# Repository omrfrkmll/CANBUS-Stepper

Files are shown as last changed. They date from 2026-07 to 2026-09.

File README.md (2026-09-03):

# ⚡ CANBUS-Stepper

<p align="center">
  <b>ESP32-S3 Based Closed-Loop Smart CAN Bus Stepper Motor Driver Board (v1.1)</b>
</p>

<p align="center">
  
  
  
  
  
  
  
</p>

<p align="center">
  <a href="#-overview">Overview</a> •
  <a href="#-development-status">Development Status</a> •
  <a href="#-hardware-features--specifications">Hardware Specs</a> •
  <a href="#-pcb--hardware-preview">PCB Preview</a> •
  <a href="#-schematics--mechanical-cad">Schematic & CAD</a> •
  <a href="#-firmware--control-sdk">Firmware & SDK</a> •
  <a href="#-official-hardware--custom-engineering">Official Hardware & Services</a> •
  <a href="#-license">License</a>
</p>

---

## 📌 Overview

**CANBUS-Stepper** is a high-performance smart stepper motor driver board powered by the **ESP32-S3** dual-core microcontroller. Designed specifically for 3D printer toolheads, robotic actuators, AGVs, CNC axes, and industrial automation, this board integrates:

- **Ultra-Quiet Motor Drive**: Trinamic TMC2209-LA driver with StealthChop2™, SpreadCycle™, and StallGuard4™ sensorless homing.
- **Closed-Loop Position Feedback**: High-precision AS5600 12-bit magnetic rotary encoder mounted coaxially on the bottom layer to eliminate missed steps.
- **Native CAN Bus Communication**: Automotive-grade TI TCAN3413 transceiver supporting high-speed CAN and CAN FD logic with 3.3V logic.
- **Industrial Wide-Input Power**: High-efficiency TI LMR33630 36V / 3A synchronous step-down DC-DC buck regulator + ultra-low-noise 3.3V LDO.
- **Multi-Stage Protection Circuits**: Reverse polarity P-MOSFET, transient voltage suppressors (TVS), ESD diode arrays, and resettable PPTC fuses.
- **Compact NEMA 17 Footprint**: Fits directly onto the rear face of standard 42mm x 42mm NEMA 17 stepper motors (40.3mm x 40.3mm profile with corner chamfers and M3 mounting holes).

---

## 🚧 Development Status

| Component | Status | Details |
| :--- | :---: | :--- |
| **Schematic Design** | ✅ Complete | Hierarchical schematic design, [PDF export available](docs/schematics/CANBUS_Stepper_v1.1_Schematic.pdf) |
| **PCB Layout (v1.1)** | ✅ Complete | 2-Layer 1.6mm FR4, DRC clean, planar ESP32-S3 pin routing |
| **Component Mapping (BOM)** | ✅ Complete | 43 unique lines / 67 components 100% mapped with LCSC part numbers |
| **3D CAD STEP Models** | ✅ Complete | Exported 3D assembly ([`step/canbus-stepper-v1.1.step`](step/canbus-stepper-v1.1.step)) ready for enclosure design |
| **Physical Prototyping** | 🔄 In Progress | Prototype PCBA fabrication & physical hardware bring-up |
| **Firmware & Control SDK** | 🔄 In Progress | ESP32-S3 TWAI CAN driver, closed-loop PID loop & Klipper node support |

---

## 🛠️ Hardware Features & Specifications

### 🧠 Core System & Processing
- **MCU**: **ESP32-S3-MINI-1-N4R2** (Dual-core Xtensa® 32-bit LX7 @ 240 MHz, 2.4 GHz Wi-Fi 4 + Bluetooth 5 LE, 4 MB Flash, 2 MB Quad SPI PSRAM).
- **USB Interface**: Native Full-Speed USB 2.0 via Type-C connector with hardware CDC serial console & JTAG debugging support.

### ⚡ Motor Drive & Closed-Loop Regulation
- **Stepper Driver**: **Trinamic TMC2209-LA** (VQFN-28 package with thermal vias).
  - Operating Voltage: Up to 28V DC (recommended 12V – 24V).
  - Current Capability: 2.0A RMS (2.8A Peak) motor phase current.
  - Features: StealthChop2™ (silent operation), SpreadCycle™ (high dynamic torque), StallGuard4™ (load measurement & sensorless homing), CoolStep™ (energy saving).
  - Interface: UART control for dynamic microstepping configuration (up to 256 microsteps) and real-time current scaling.
- **Position Sensor**: **AMS AS5600-ASOT** 12-Bit On-Axis Magnetic Rotary Encoder.
  - Position Resolution: 4096 steps/rev (0.087° resolution).
  - Mounting: Centered directly on PCB bottom layer for coaxial alignment with motor shaft diametral magnet.
  - Interface: Fast-mode I2C (400 kHz).

### 🌐 Bus Communication & Power Regulation
- **CAN Bus Transceiver**: **TI TCAN3413DRBR** 3.3V CAN FD Transceiver with 3.3V V_IO logic interface and ±58V bus fault protection.
- **Main DC-DC Buck Converter**: **TI LMR33630CRNXR** Synchronous Step-Down Regulator (3.8V – 36V input range, 3.0A continuous output @ 2.1 MHz switching frequency) with **Changjiang FNR4020S4R7MT** (4.7µH / 2A) shielded power inductor.
- **MCU & Analog LDO**: **TI TLV75533PDRVR** 500mA ultra-low-dropout 3.3V regulator providing clean power to ESP32-S3 and sensors.
- **Bulk Filtering**: 100µF / 35V Low-ESR aluminum electrolytic bulk capacitor (6.3mm x 5.8mm SMD) for motor switching current ripple suppression.

### 🛡️ Protection & Safety Architecture
- **Reverse Polarity Protection**: **AON7403** (-30V / -50A, 8.5mΩ R_DS(on) P-Channel MOSFET) with Zener gate clamping.
- **Overcurrent Protection**:
  - 1.5A / 24V Resettable PPTC fuse (`1210L150/24WR`) on main 24V DC input rail.
  - 500mA / 16V Resettable PPTC fuse (`SMDH0805B050TF`) on USB VBUS power line.
- **Transient & ESD Protection**:
  - **PESD1CAN** TVS diode array on CAN Bus differential lines (CAN_H / CAN_L).
  - **SMAJ28A** 28V / 400W Transient Voltage Suppressor on main 24V DC input.
  - **STMicroelectronics USBLC6-2P6** ultra-low capacitance ESD protection array on USB D+/D- lines.
  - **MBR0520** Schottky diode for safe USB/Main power OR-ing.

### 🔌 Connectors, Ports & Controls
| Connector / Component | Type / Footprint | Function |
| :--- | :--- | :--- |
| **USB-C** | 16-Pin USB Type-C Receptacle | Firmware flashing, USB CDC serial debugging & power |
| **24V Power In / Out** | 2x Molex Micro-Fit 3.0 (436500209) 2-Pin | 24V Main power input & daisy-chain pass-through |
| **Motor Output** | JST PH 4-Pin SMD (S4B-PH-SM4-K-TB) | 4-wire bipolar stepper motor phases (A1, A2, B1, B2) |
| **Qwiic / I2C Port** | JST SH 4-Pin (1.0mm) Horizontal | External I2C sensors, OLED displays & expansions (3.3V, GND, SDA, SCL) |
| **AUX Port** | JST SH 4-Pin (1.0mm) Horizontal | Auxiliary GPIOs for endstops, bed probes, or toolhead sensors |
| **CAN Bus In / Out** | 2x JST SH 2-Pin (SM02B-SRSS-TB) | CAN Bus differential input & daisy-chain pass-through (CAN_H, CAN_L) |
| **OLED Display FPC** | Amphenol SFV30R-2STBE1HLF (30-Pin 0.5mm) | Bare COG OLED display panel interface (SSD1306) |
| **CAN Termination** | SMD Slide Switch (`MSK12C01G15-W`) | Switchable 120Ω CAN bus termination resistor |
| **Buttons & Indicators** | 2x Tactile Push-Buttons + 3x LEDs | RESET, BOOT/User buttons; Power, Driver, and CAN Status LEDs |

---

## 🖼️ PCB & Hardware Preview

<p align="center">
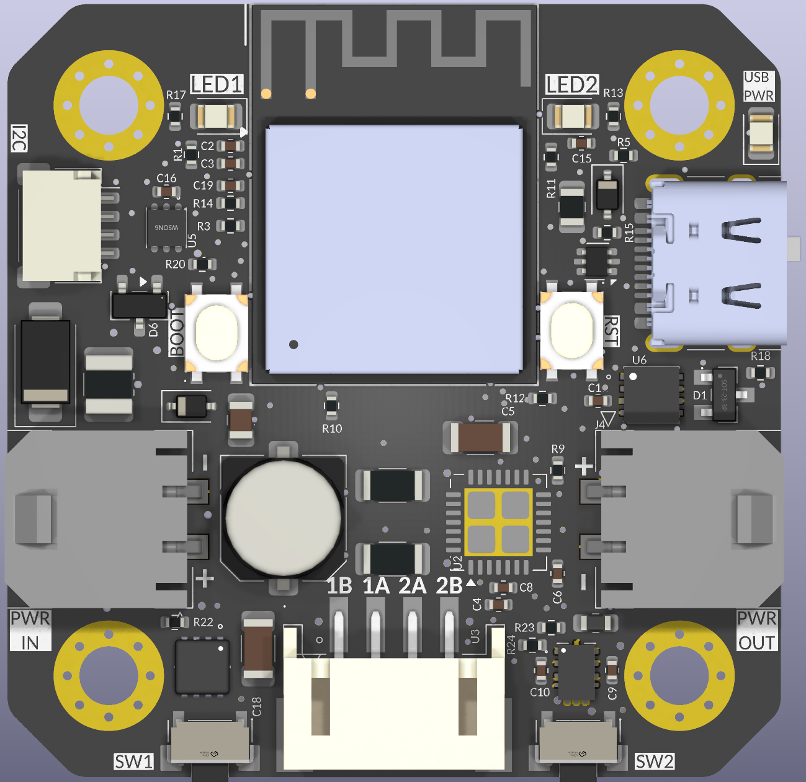
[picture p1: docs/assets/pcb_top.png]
CANBUS-Stepper PCB Top Side
  
  &nbsp;&nbsp;
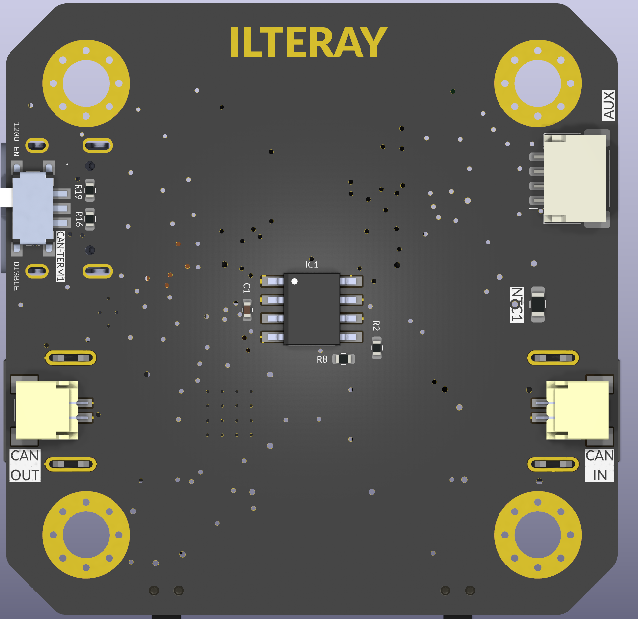
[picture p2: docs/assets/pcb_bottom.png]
CANBUS-Stepper PCB Bottom Side
  
  <br>
  <i>Figure 1: CANBUS-Stepper v1.1 Component Layout — Top Layer (Left) & Bottom Layer (Right)</i>
</p>

---

## 📄 Schematics & Mechanical CAD

To enable seamless third-party software integration, driver development, and custom enclosure modeling, official hardware reference documents are provided:

1. **Schematic Circuit Diagrams (PDF)**:
   - Complete multi-sheet reference schematics are available in [`docs/schematics/CANBUS_Stepper_v1.1_Schematic.pdf`](docs/schematics/CANBUS_Stepper_v1.1_Schematic.pdf) (Legacy v1.0 available in [`docs/schematics/`](docs/schematics/)).
   - Details MCU pinouts, TMC2209 UART buses, CAN transceiver wiring, protection circuits, and sensor connectors.
2. **3D Mechanical STEP Assembly**:
   - Ready-to-import 3D CAD model: [`step/canbus-stepper-v1.1.step`](step/canbus-stepper-v1.1.step).
   - Accurate component heights, connector positions, and NEMA 17 rear mounting hole spacing (31.0mm x 31.0mm diagonal M3 holes).

---

## 📁 Repository Structure

```
CANBUS-Stepper/
├── README.md                      # Main project documentation & specifications
├── LICENSE                        # CC BY-NC-SA 4.0 (Hardware Reference) & MIT (Software)
├── .gitignore                     # Git ignore rules
├── docs/
│   ├── assets/                    # 3D PCB renders, board photos, and diagrams
│   └── schematics/                # Full PDF Schematic & Pinout reference documentation
│       ├── README.md              # Sheet breakdown and integration guide
│       └── CANBUS_Stepper_v1.1_Schematic.pdf
├── firmware/                      # ESP32-S3 Firmware, Protocol & SDK
│   ├── include/                   # Drivers, control loops, and headers
│   ├── src/                       # Motion controller, TWAI CAN, AS5600, TMC2209
│   ├── klipper/                   # Klipper toolhead configuration & docs
│   ├── platformio.ini             # PlatformIO build configuration
│   └── README.md                  # Firmware architecture & roadmap
└── step/                          # 3D CAD STEP Files for mechanical integration
    ├── canbus-stepper-v1.1.step   # Full 3D PCB assembly STEP model (v1.1)
    └── README.md                  # Mounting specifications & CAD guide
```

---

## 🧠 Firmware & Control SDK

The ESP32-S3 microcontroller firmware is developed under `firmware/` and targets both standalone robotic motion control and 3D printing ecosystems:

- **TWAI CAN Protocol**: High-speed command parser for position target streaming, velocity profiling, and status telemetry.
- **Closed-Loop PID Loop**: High-frequency reading from the AS5600 magnetic encoder with real-time step error correction and missed step prevention.
- **Klipper CAN Toolhead Support**: Compatibility with Klipper firmware for plug-and-play toolhead CAN node integration.
- **ROS2 & Micro-ROS**: Direct actuator node integration for robotic arms, wheeled rovers, and multi-axis mechanisms.
- **Open SDK**: Python and C++ driver libraries for controlling motors over USB-to-CAN adapters.

---

## 🛒 Official Hardware, Kits & Custom Engineering

Ensure guaranteed hardware quality and support ongoing development through **Official Pre-Assembled Hardware & Engineering Services**:

### 📦 Official Plug-and-Play Kits
- 🛠️ **Factory-Tested Boards**: 100% SMT assembled, flashed with factory test firmware, and validated under motor load.
- 🧲 **Complete Motor Kits**: Bundled with high-temperature NEMA 17 stepper motors, matched diametrically magnetized shaft magnets, 3D printed mounting brackets, and pre-crimped Molex/JST wire harnesses.
- ☕ **Support Ongoing Development**: Official hardware sales directly fund continuous firmware development, Klipper modules, and future hardware revisions.

### 🏢 B2B Custom Robotics & Turnkey Engineering
Need customized hardware or industrial integration for your commercial robotics or automation project?
- **Custom PCB Redesigns** (Multi-axis drivers, 48V high-voltage input, RS485 / EtherCAT / DroneCAN).
- **Industrial Firmware & ROS2 / Micro-ROS Drivers**.
- **Volume Batch Manufacturing & PCBA Sourcing**.

👉 *For pre-orders, volume batch requests, or custom engineering consulting, please reach out via GitHub Issues or contact the maintainer.*

---

## 📜 License

This project follows a **Hybrid Open-Software & Reference-Hardware** model:

- 🛡️ **Hardware Reference (Schematics, Pinouts, Mechanical Specs & 3D STEP)**: [Creative Commons Attribution-NonCommercial-ShareAlike 4.0 International (CC BY-NC-SA 4.0)](https://creativecommons.org/licenses/by-nc-sa/4.0/).
- 💻 **Firmware & Software Stack**: [MIT License](LICENSE).
- 🏷️ **Trademarks & Official Branding**: The "CANBUS-Stepper" and "ILTERAY" names and logos represent official tested hardware.

---

<p align="center">
  <b>CANBUS-Stepper</b> • Open-Source Smart Motion Control
</p>

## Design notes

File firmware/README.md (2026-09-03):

# 🧠 CANBUS-Stepper Firmware & Control SDK

This directory contains the firmware architecture, CAN bus communication protocol, and control SDK for the **ESP32-S3** microcontroller on the **CANBUS-Stepper** closed-loop driver board.

---

## 🏗️ Architecture & Core Components

- **Target MCU**: ESP32-S3-MINI-1-N4R2 (Dual-core Xtensa LX7 @ 240MHz, 4MB Flash, 2MB PSRAM)
- **Framework**: ESP-IDF v5.x / Arduino ESP32 Core
- **Motor Control**: Trinamic TMC2209-LA via UART (microstepping, StealthChop2, StallGuard4 sensorless homing) + Step/Dir pulse generation.
- **Closed-Loop Feedback**: AS5600 12-Bit Magnetic Rotary Encoder via fast hardware I2C (400kHz), running high-frequency angle reading & real-time PID position error correction.
- **Communication Stack**: ESP32-S3 Native TWAI (Two-Wire Automotive Interface) CAN Bus driver via TI TCAN3413 transceiver.

---

## 🗺️ Firmware Development Roadmap

- [ ] **Phase 1: Board Bring-up & Diagnostics**
  - [x] Hardware pinout mapping & peripheral definitions.
  - [ ] Power rail validation, I2C bus scanner (AS5600 detection & magnet field strength check).
  - [ ] TMC2209 UART communication & register read/write tests.
  - [ ] Native USB CDC serial console & web flasher integration.

- [ ] **Phase 2: Motor Motion & Closed-Loop Control**
  - [ ] High-frequency RMT / Timer-based step pulse generation with acceleration curves.
  - [ ] Closed-loop PID position regulator using AS5600 feedback.
  - [ ] Stall detection, missed step recovery, and overload protection.

- [ ] **Phase 3: Bus Protocols & Ecosystem Integration**
  - [ ] Standardized CAN Bus binary packet protocol (Position, Velocity, Current, Status telemetry).
  - [ ] **Klipper CAN Bus Toolhead / Stepper Node** protocol compatibility.
  - [ ] **Micro-ROS / ROS2** actuator node support for robotic arms and AGVs.
  - [ ] Open-source Python & C++ client SDKs with GUI motor tuning tools.

---

## 🤝 Contributing
Firmware contributions, issue reports, and feature requests are warmly welcomed! Please refer to the main repository [LICENSE](../LICENSE) (MIT License).

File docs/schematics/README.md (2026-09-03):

# 📄 CANBUS-Stepper Hardware Schematics

This directory contains the official reference schematic diagrams for the **CANBUS-Stepper** smart closed-loop stepper motor driver board.

## 📑 Available Documentation

- **v1.1 Schematic Diagram (PDF - Latest)**: [`CANBUS_Stepper_v1.1_Schematic.pdf`](CANBUS_Stepper_v1.1_Schematic.pdf)
  - Updated ESP32-S3 planar pinout & non-crossing routing optimization
  - Sheet 1: ESP32-S3-MINI-1 Microcontroller, USB Type-C & Power OR-ing
  - Sheet 2: Trinamic TMC2209-LA Motor Driver & Current Sensing
  - Sheet 3: AS5600 12-bit Magnetic Encoder & Sensor Interfaces (Qwiic, NTC, AUX)
  - Sheet 4: TI TCAN3413 CAN FD Transceiver & 120Ω Switchable Termination
  - Sheet 5: TI LMR33630 36V/3A DC-DC Buck Converter, Protection & 3.3V LDO
- **v1.0 Schematic Diagram (PDF - Legacy)**: [`CANBUS_Stepper_v1.0_Schematic.pdf`](CANBUS_Stepper_v1.0_Schematic.pdf)

## 🛡️ License & Usage

- **Schematics & Pinout Reference**: Licensed under [Creative Commons Attribution-NonCommercial-ShareAlike 4.0 (CC BY-NC-SA 4.0)](https://creativecommons.org/licenses/by-nc-sa/4.0/).
- For commercial hardware manufacturing inquiries, official pre-assembled boards, or volume orders, please contact the maintainers.

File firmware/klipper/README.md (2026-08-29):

# 🖨️ Klipper & Katapult (CanBoot) Setup Guide

This guide explains how to compile and flash **Klipper** or **Katapult (CanBoot)** onto the **CANBUS-Stepper v1.1** board to use it as a high-speed CAN bus stepper / toolhead node in 3D printers and CNC machines.

---

## 🛠️ 1. Compiling Katapult Bootloader

Katapult allows future firmware updates to be flashed directly over the CAN bus without plugging in a USB cable.

1. Clone Katapult:
   ```bash
   git clone https://github.com/Arksine/katapult
   cd katapult
   make menuconfig
   ```

2. Configure Katapult settings for **ESP32-S3**:
   - **Micro-controller Architecture**: `Espressif ESP32`
   - **Processor model**: `esp32s3`
   - **Communication interface**: `CAN bus`
   - **CAN RX gpio number**: `47`
   - **CAN TX gpio number**: `48`
   - **CAN bus speed**: `500000` (or `1000000` for 1M)
   - **Status LED pin**: `10`

3. Compile and flash over USB:
   ```bash
   make
   esptool.py --chip esp32s3 -p /dev/ttyACM0 write_flash 0x0 out/katapult.bin
   ```

---

## 🚀 2. Compiling Klipper MCU Firmware

1. Open Klipper menuconfig:
   ```bash
   cd ~/klipper
   make menuconfig
   ```

2. Select the following parameters:
   - **Enable extra low-level configuration options**: `[ * ]`
   - **Micro-controller Architecture**: `Espressif ESP32`
   - **Processor model**: `esp32s3`
   - **Communication interface**: `CAN bus`
   - **CAN RX gpio number**: `47`
   - **CAN TX gpio number**: `48`
   - **CAN bus speed**: `500000` (or your CAN network speed)

3. Compile Klipper:
   ```bash
   make
   ```

4. Flash Klipper over CAN Bus via Katapult:
   ```bash
   python3 ~/katapult/scripts/flashtool.py -i can0 -u <YOUR_CANBUS_UUID> -r
   python3 ~/katapult/scripts/flashtool.py -i can0 -u <YOUR_CANBUS_UUID> -f ~/klipper/out/klipper.bin
   ```

---

## 📄 3. Integrating with `printer.cfg`

Copy the provided [`canbus_stepper_klipper.cfg`](canbus_stepper_klipper.cfg) configuration into your Klipper configuration directory and include it in `printer.cfg`:

```ini
[include canbus_stepper_klipper.cfg]
```

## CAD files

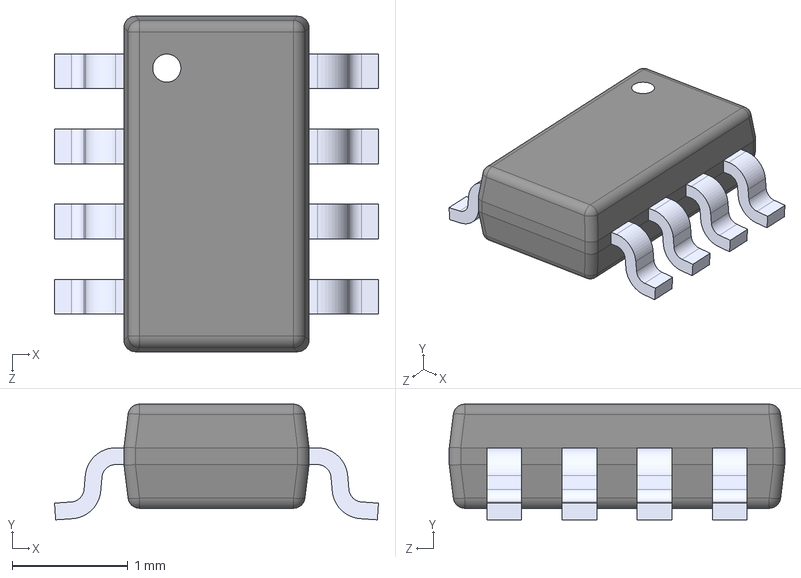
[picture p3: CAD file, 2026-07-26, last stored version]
3dmodels/MP2315GJ.step
2.80 x 1 x 2.90 mm

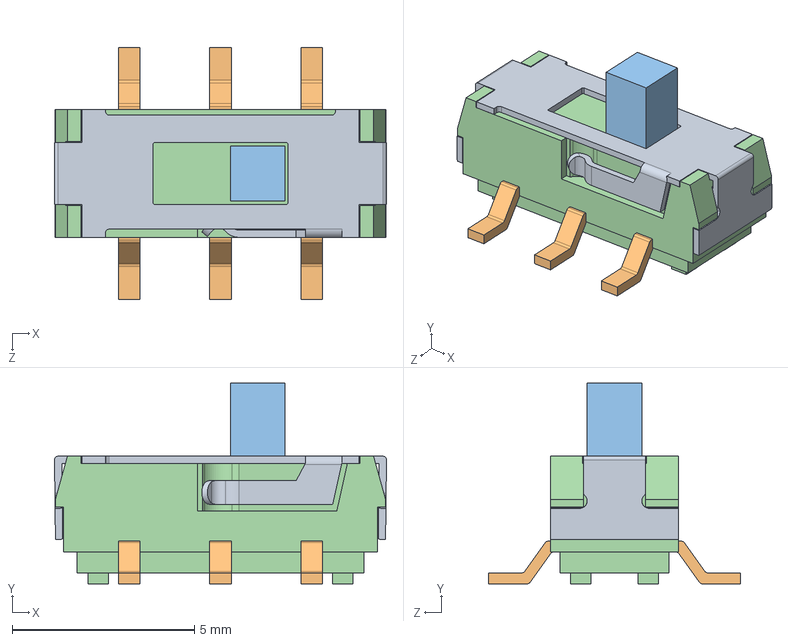
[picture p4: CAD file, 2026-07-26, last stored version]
3dmodels/SLW-913535-2A-SMT.step
9.10 x 5.50 x 6.90 mm

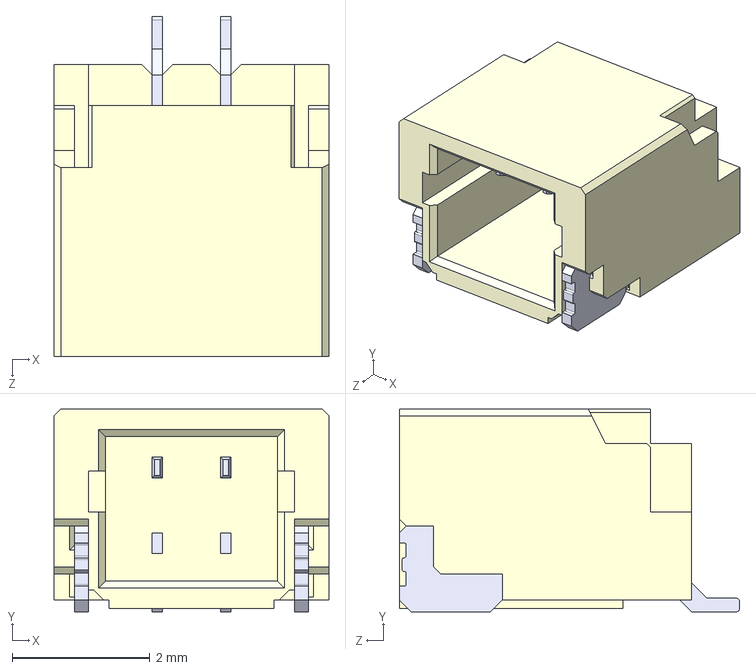
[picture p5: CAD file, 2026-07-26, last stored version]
3dmodels/SM02B-SRSS-TB_LF__SN_.step
4.00 x 2.95 x 4.95 mm

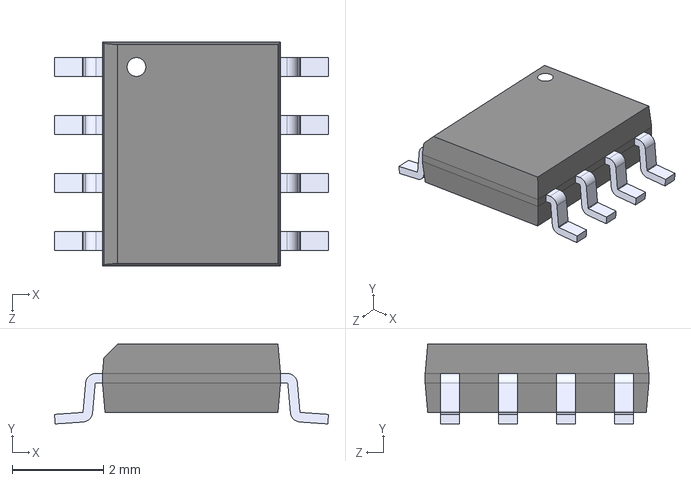
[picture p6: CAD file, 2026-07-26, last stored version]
3dmodels/AS5600-ASOT.step
6.00 x 1.75 x 4.90 mm

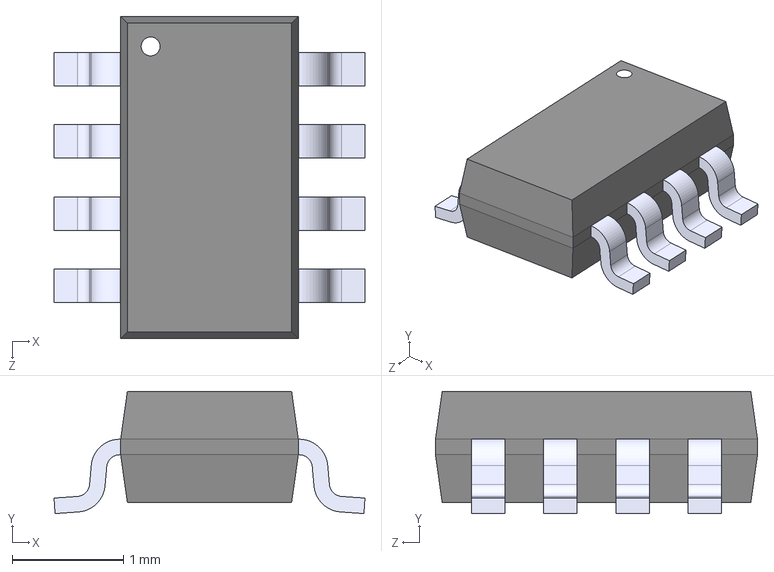
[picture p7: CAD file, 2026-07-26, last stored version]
3dmodels/TCAN1044VDDFRQ1.step
2.80 x 1.10 x 2.90 mm

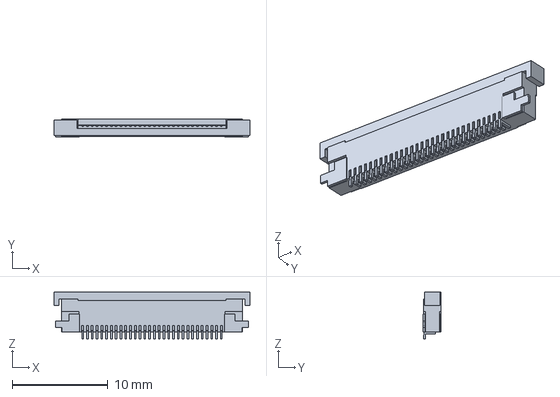
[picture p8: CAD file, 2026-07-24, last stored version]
3dmodels/SFV30R-2STBE1HLF.step
20.5 x 1.87 x 4.90 mm

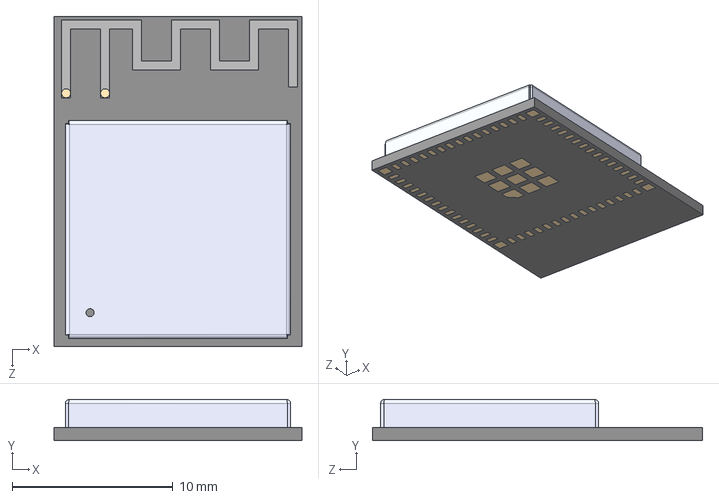
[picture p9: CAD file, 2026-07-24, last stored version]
3dmodels/ESP32-S3-MINI-1-N4R2.step
15.4 x 2.55 x 20.5 mm

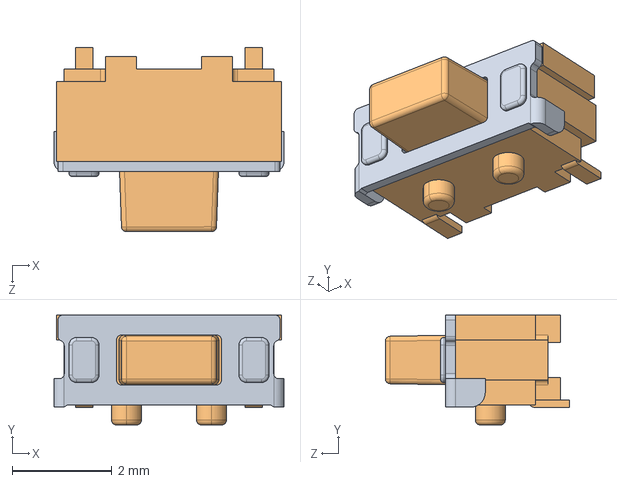
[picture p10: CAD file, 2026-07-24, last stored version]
3dmodels/TS31-46-35-BK-B-160-RA-SMT-TR.step
4.60 x 2.20 x 3.69 mm

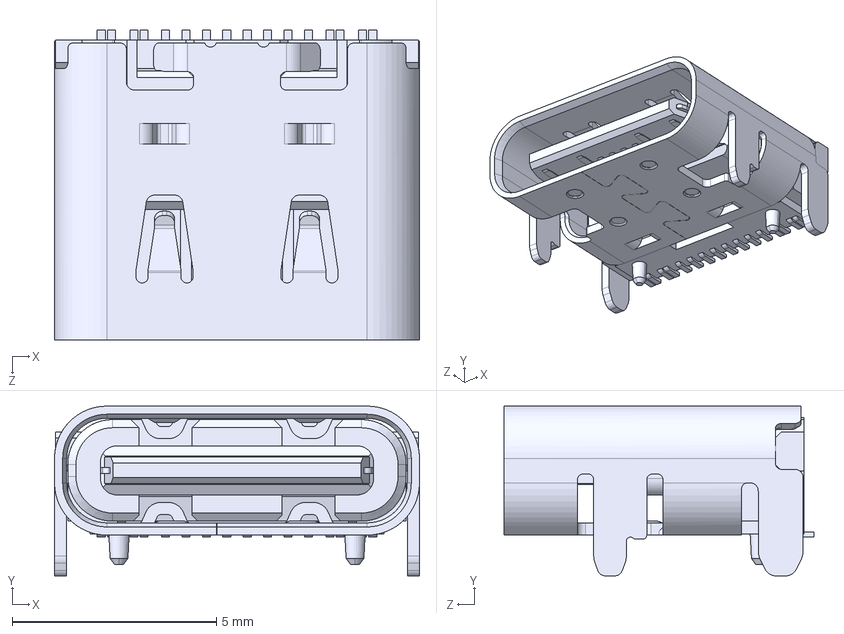
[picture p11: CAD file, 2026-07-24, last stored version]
3dmodels/USB_C_Receptacle.step
8.94 x 4.16 x 7.60 mm

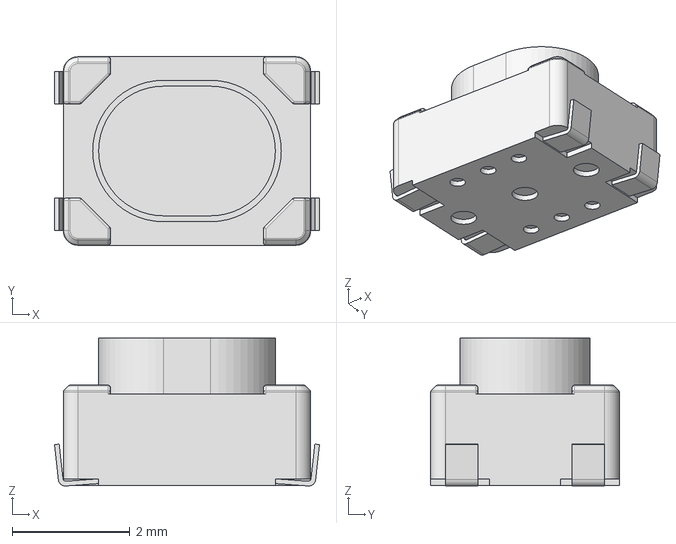
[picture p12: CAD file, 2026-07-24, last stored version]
3dmodels/TL3365AF180QG.step
4.50 x 3.20 x 2.51 mm

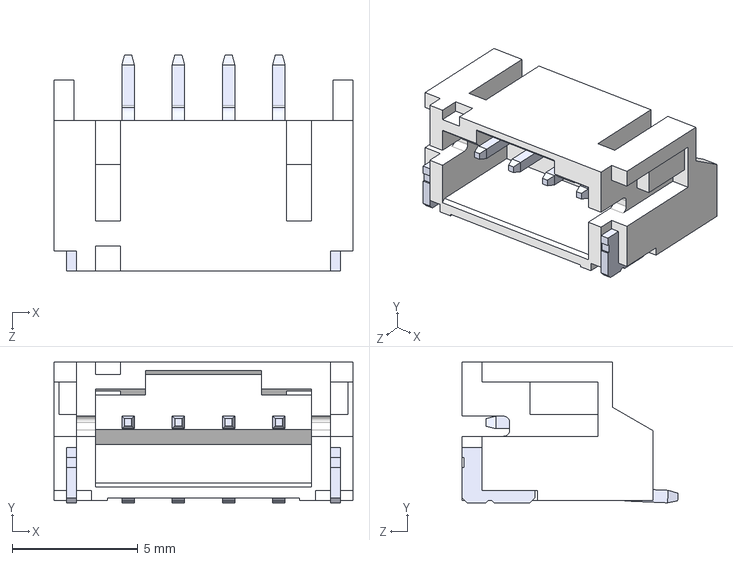
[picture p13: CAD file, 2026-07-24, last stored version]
3dmodels/S4B-PH-SM4-TB.step
11.9 x 5.60 x 8.60 mm

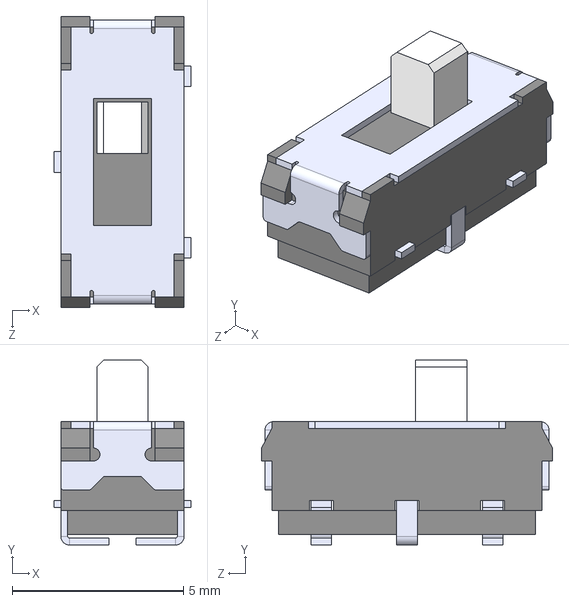
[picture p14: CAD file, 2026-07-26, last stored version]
3dmodels/JS102011JCQN.step
4.00 x 5.40 x 8.50 mm

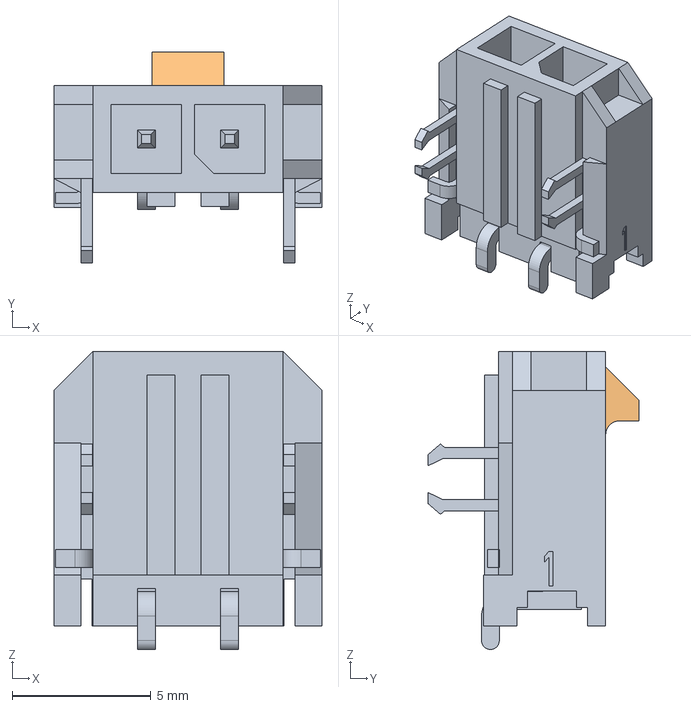
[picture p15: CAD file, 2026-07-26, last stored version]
3dmodels/436500209.step
9.65 x 7.60 x 10.7 mm

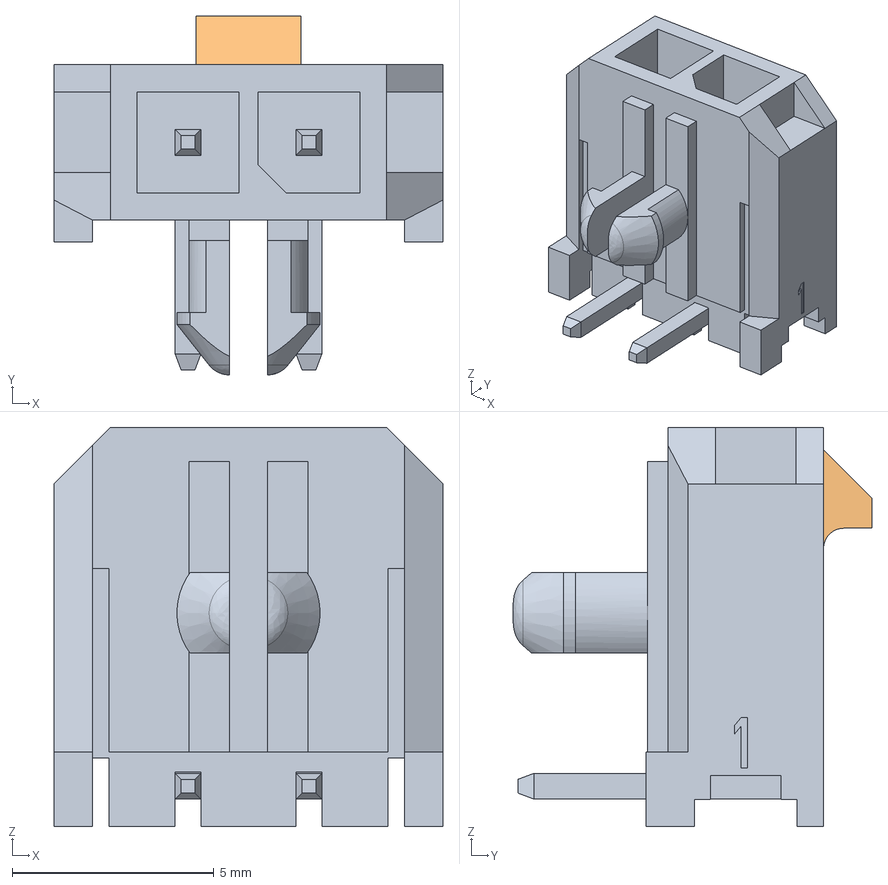
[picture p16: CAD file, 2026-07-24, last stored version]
3dmodels/436500201.step
9.65 x 8.91 x 9.90 mm

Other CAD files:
3dmodels/436500212.step

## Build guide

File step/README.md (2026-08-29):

# 📐 3D CAD STEP Models & Mechanical Integration

This directory contains the exported 3D CAD models of the **CANBUS-Stepper** PCB assemblies.

---

## 📦 Files Included

- **`canbus-stepper-v1.1.step`** (Latest): High-detail 3D STEP assembly containing accurate 3D CAD models of all surface-mount components, connectors (USB-C, Molex Micro-Fit 3.0, JST PH/SH, FPC), tactile switches, and PCB routing geometry for v1.1 production release.
- **`canbus-stepper-v1.0.step`** (Legacy): Initial v1.0 hardware release 3D CAD STEP model.

---

## 🎯 Mechanical & Mounting Specifications

| Parameter | Specification |
| :--- | :--- |
| **PCB Dimensions** | 40.3mm x 40.3mm (Chamfered corner profile with 8-fillet outline) |
| **Compatibility** | Direct rear-mount on **NEMA 17** stepper motors (42mm x 42mm) |
| **Mounting Holes** | 4x M3 screw holes (31.0mm x 31.0mm standard pitch) |
| **Magnetic Sensor Position** | AS5600 IC centered precisely on the bottom face for coaxial shaft magnet alignment |
| **Recommended Magnet Gap** | 0.5mm – 1.5mm air gap between motor shaft diametral magnet and AS5600 package |

---

## 💻 CAD Software Compatibility
These STEP models can be imported directly into:
- Autodesk Fusion 360 / Inventor
- SolidWorks
- FreeCAD
- Blender / OnShape

Use these models to design custom 3D printed enclosures, toolhead brackets, cooling fan shrouds, and robotic joints.

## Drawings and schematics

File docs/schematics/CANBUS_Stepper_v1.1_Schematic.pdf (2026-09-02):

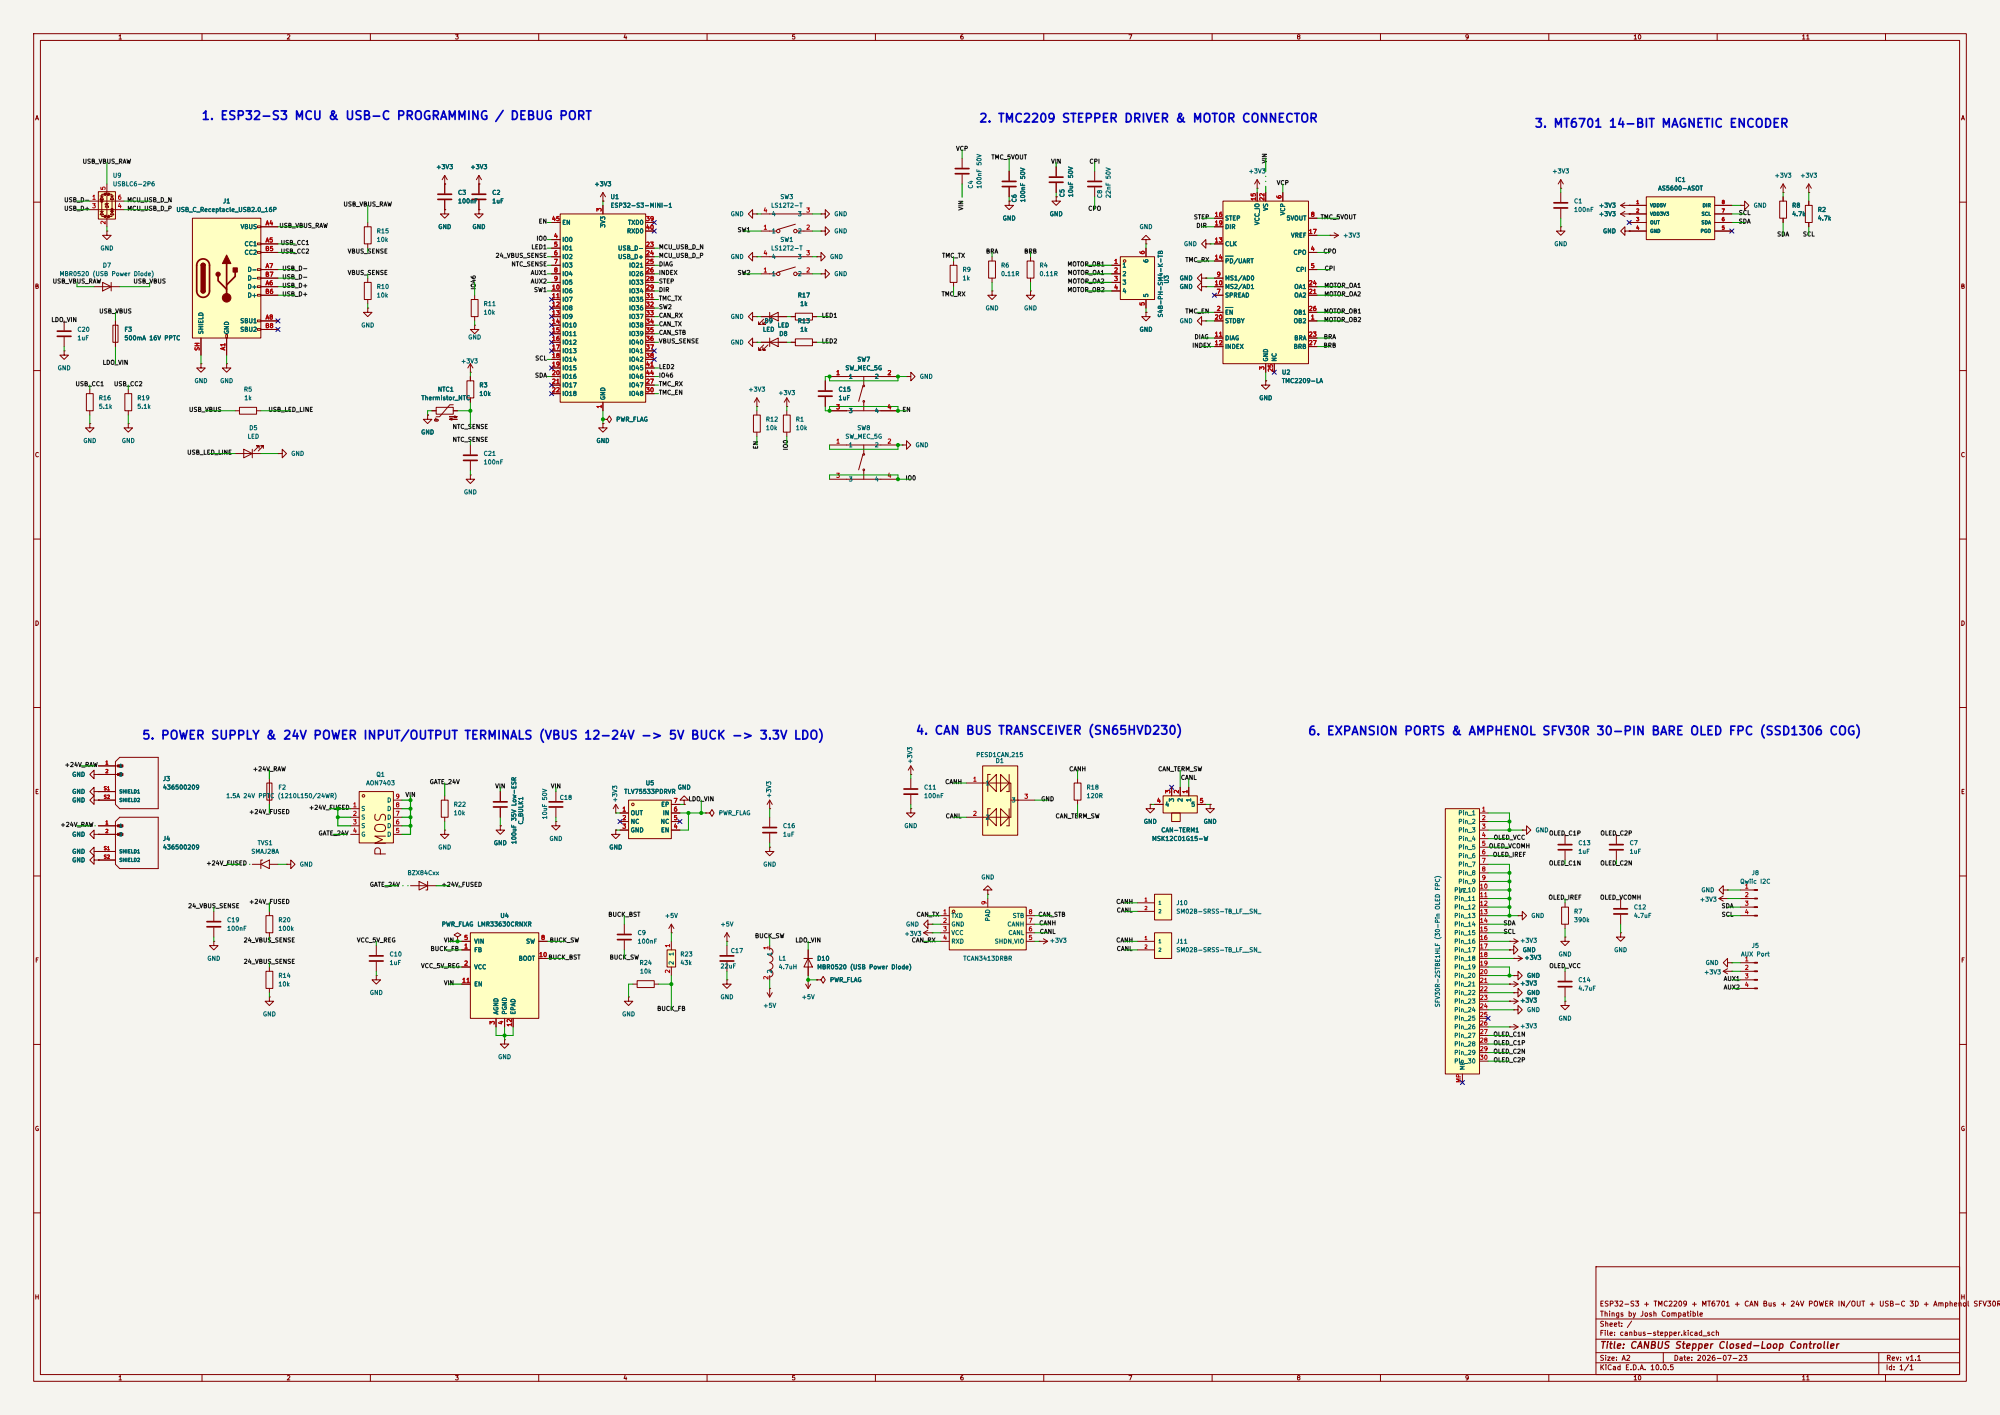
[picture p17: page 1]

5. POWER SUPPLY & 24V POWER INPUT/OUTPUT TERMINALS (VBUS 12-24V -> 5V BUCK -> 3.3V LDO)

ESP32-S3 + TMC2209 + MT6701 + CAN Bus + 24V POWER IN/OUT + USB-C 3D + Amphenol SFV30R
Things by Josh Compatible
Sheet: /
File: canbus-stepper.kicad_sch
Title: CANBUS Stepper Closed-Loop Controller

Size: A2 | Rev: v1.1
KiCad E.D.A. 10.0.5 | Id: 1/1

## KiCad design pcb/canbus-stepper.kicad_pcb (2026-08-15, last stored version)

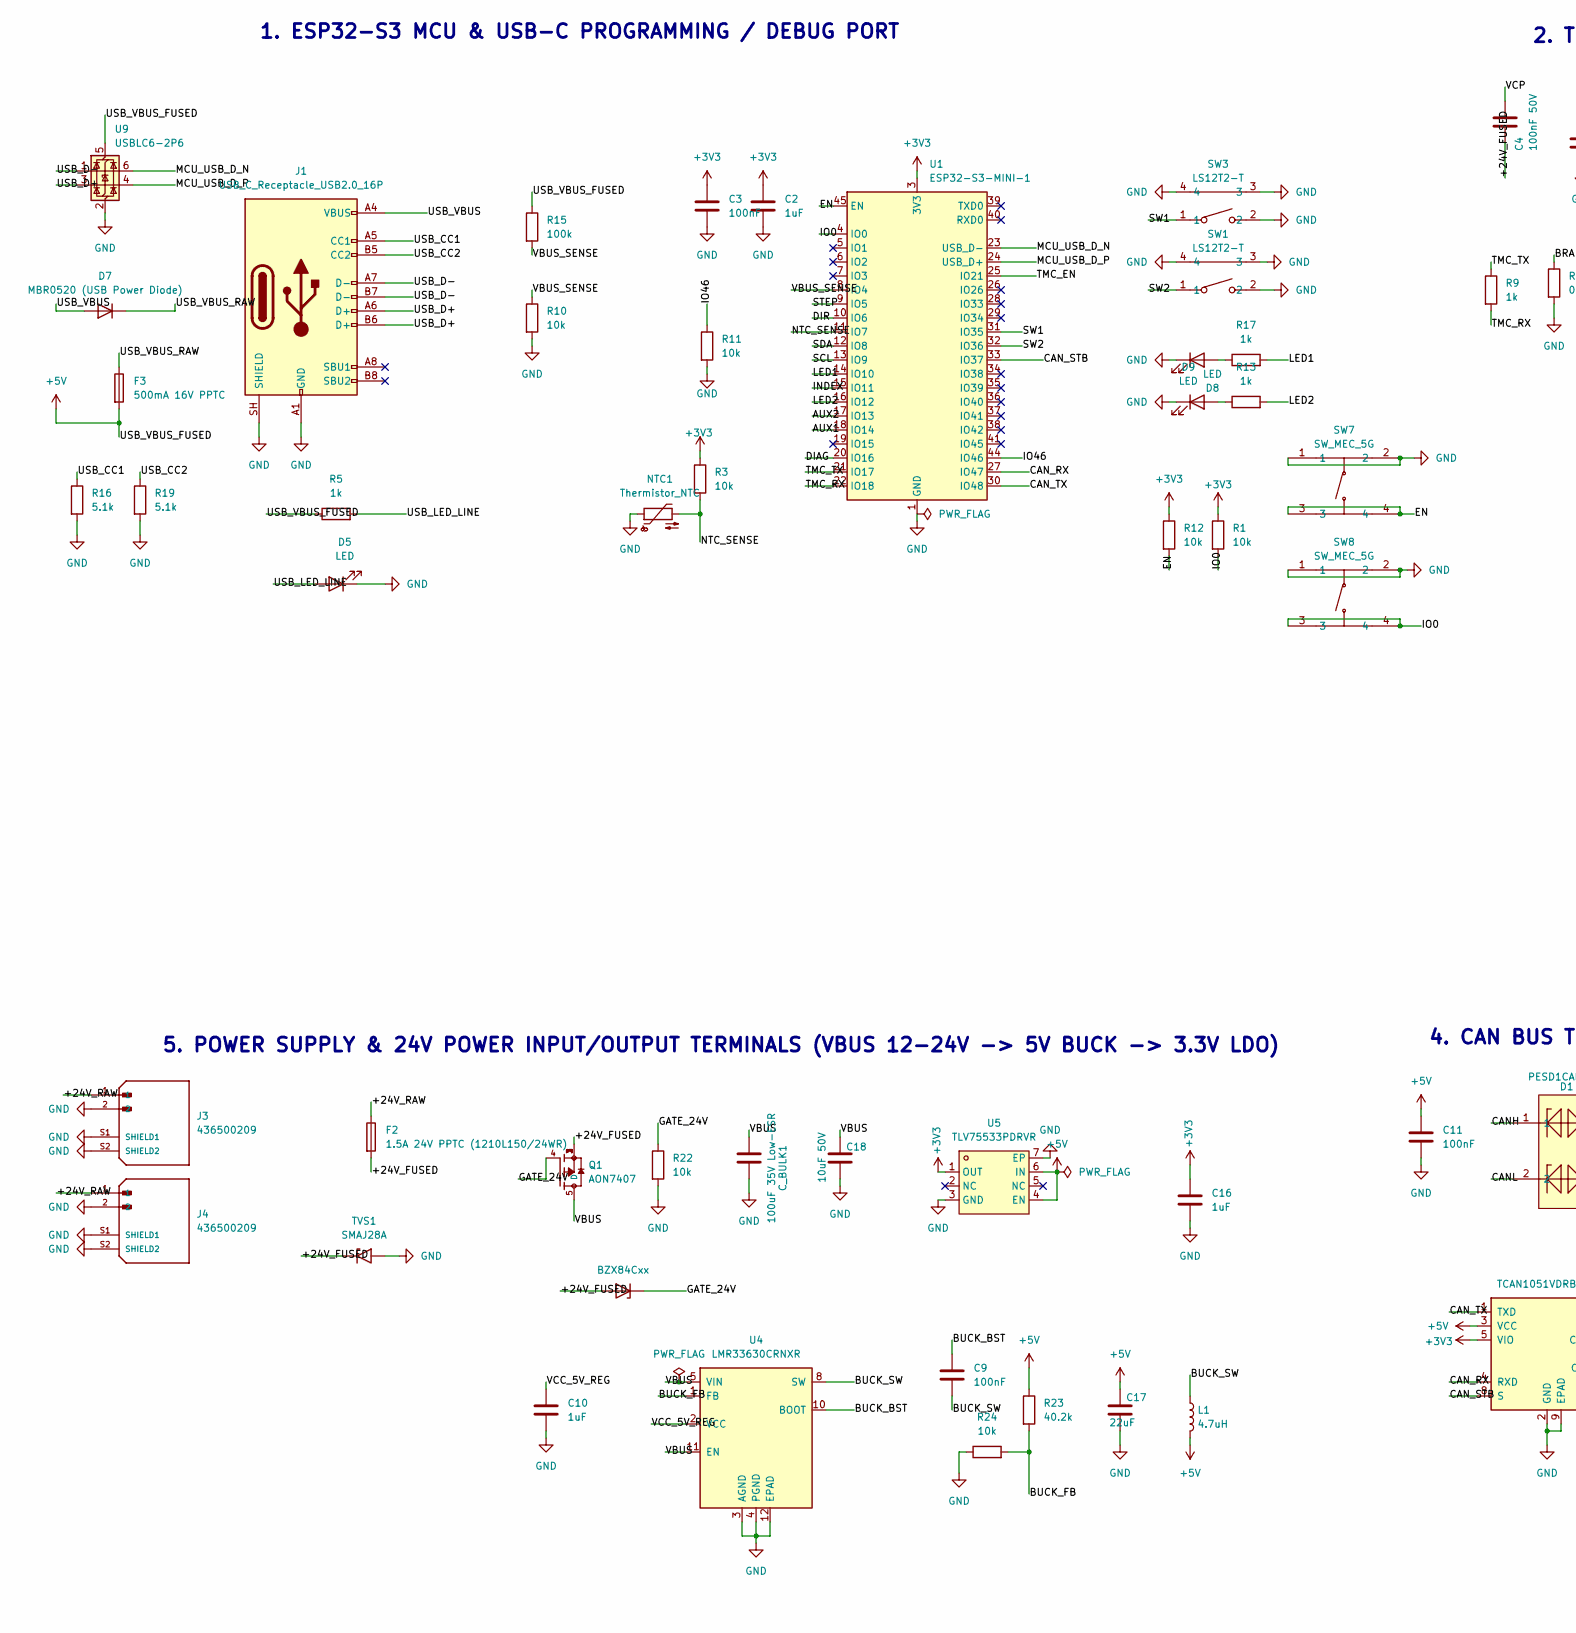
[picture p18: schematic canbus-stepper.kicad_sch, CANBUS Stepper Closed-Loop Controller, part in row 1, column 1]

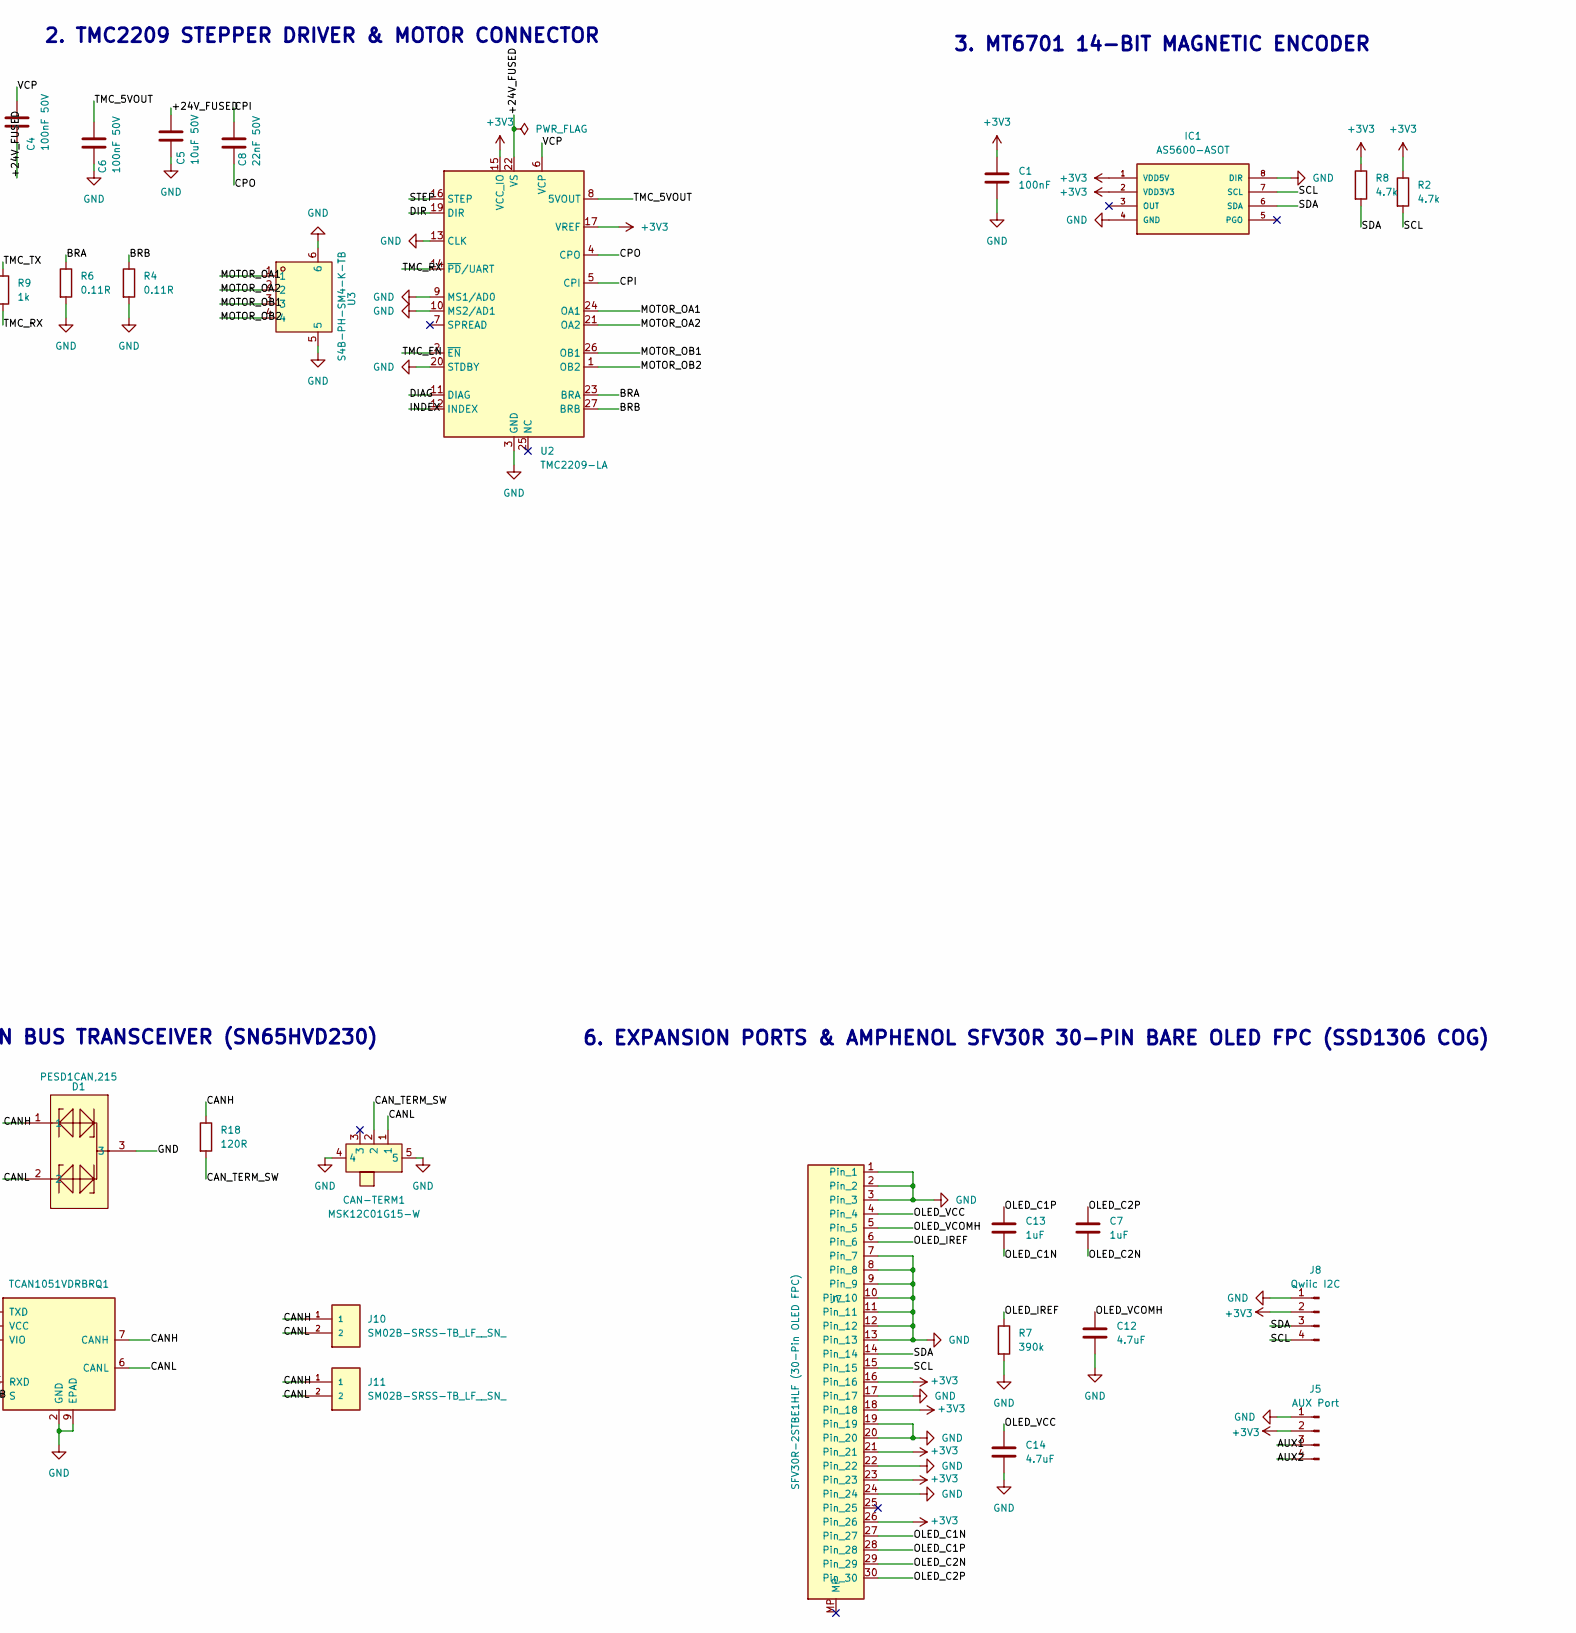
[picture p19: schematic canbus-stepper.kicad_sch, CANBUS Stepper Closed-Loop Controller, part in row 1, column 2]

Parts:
C1, C3, C9, C11: 100nF; C_0402_1005Metric; DigikeyPN GCM155R71H104KE02J
C2, C10, C16: 1uF; C_0402_1005Metric; DigikeyPN JMK105BJ105KV-F
C4, C6: 100nF 50V; C_0402_1005Metric; DigikeyPN GRM155R71H104KE14J
C5, C18: 10uF 50V; C_1206_3216Metric; DigikeyPN 885012108022
C7, C13: 1uF; C_0402_1005Metric; DigikeyPN 478-KGM05AR50J105KHCT-ND
C8: 22nF 50V; C_0402_1005Metric; DigikeyPN GRM155R71H223KA12D
C12, C14: 4.7uF; C_0402_1005Metric; LCSC Part C23733
C17: 22uF; C_0805_2012Metric; DigikeyPN CL21A226KPCLRNC
CAN-TERM1: MSK12C01G15-W; SW-SMD_MSK12C01G15-W; MPN MSK12C01G15-W; LCSC Part C22435664
C_BULK1: 100uF 35V Low-ESR; C_Elec_6.3x5.8; DigikeyPN EEH-ZK1V101XP
D1: PESD1CAN,215; SOT-23_L2.9-W1.3-P1.90-LS2.4-BR; MPN PESD1CAN,215; LCSC Part C15771
D5, D8, D9: LED; LED_0805_2012Metric; DigikeyPN LTST-C171GKT,LTST-C171KRKT
D6: BZX84Cxx; SOT-23; DigikeyPN BZX84C12LT1G
D7: MBR0520 (USB Power Diode); D_SOD-323; DigikeyPN MBR0520L
F2: 1.5A 24V PPTC (1210L150/24WR); Fuse_1210_3225Metric; DigikeyPN 2920L330/24MR
F3: 500mA 16V PPTC; Fuse_0805_2012Metric; DigikeyPN SMDH0805B050TF
IC1: AS5600-ASOT; MOUSER_PART_NUMBER 985-AS5600-ASOT
J1: USB_C_Receptacle_USB2.0_16P; USB_C_Receptacle_16P; DigikeyPN UJ20-C-H-G-SMT-4-P16-TR
J3, J4: 436500209; MOLEX_436500209; PARTREV E2; DigikeyPN 0436500209
J5: AUX Port; JST_SH_SM04B-SRSS-TB_1x04-1MP_P1.00mm_Horizontal; DigikeyPN SM02B-SRSS-TB
J7: SFV30R-2STBE1HLF (30-Pin OLED FPC); AMPHENOL_SFV30R-2STBE1HLF; DigikeyPN SFV30R-2STBE1HLF
J8: Qwiic I2C; JST_SH_SM04B-SRSS-TB_1x04-1MP_P1.00mm_Horizontal; DigikeyPN SM02B-SRSS-TB
J10, J11: SM02B-SRSS-TB_LF__SN_; DigikeyPN SM02B-SRSS-TB
L1: 4.7uH; L_0603_1608Metric; DigikeyPN MLZ1608M4R7WT000
NTC1: Thermistor_NTC; R_0603_1608Metric; DigikeyPN NCU18WF104E60RB
Q1: AON7407; PARTREV 0; DigikeyPN AON7407
R1, R3, R10, R11, R12, R22, R24: 10k; R_0402_1005Metric; DigikeyPN CRGCQ0402J10K
R2, R8: 4.7k; R_0402_1005Metric; DigikeyPN RC0402FR-074K7L
R4, R6: 0.11R; R_1206_3216Metric; DigikeyPN ERJ-8BSFR11V
R5, R9, R13, R17: 1k; R_0402_1005Metric; DigikeyPN RC0402JR-071KL
R7: 390k; R_0402_1005Metric; LCSC Part C25557
R15: 100k; R_0402_1005Metric; DigikeyPN CRGCQ0402J100K
R16, R19: 5.1k; R_0402_1005Metric; DigikeyPN RC0402FR-075K1L
R18: 120R; R_0402_1005Metric; DigikeyPN RC0402JR-07120RL
R23: 40.2k; R_0402_1005Metric; DigikeyPN RC0402FR-0740K2L
SW1, SW3: LS12T2-T; SW-SMD_2P-TS24CA; MPN TS24CA; LCSC Part C393942
SW7, SW8: SW_MEC_5G; SW-SMD_4P-L4.2-W3.4-P2.15-LS5.2; MPN TS3425PA 250gf; DigikeyPN TL3365AF180QG
TVS1: SMAJ28A; D_SMA; DigikeyPN SMAJ28A
U1: ESP32-S3-MINI-1; ESP32-S2-MINI-1; DigikeyPN ESP32-S3-MINI-1-N4R2
U2: TMC2209-LA; VQFN-28-1EP_5x5mm_P0.5mm_EP3.7x3.7mm_ThermalVias; DigikeyPN TMC2209-LA-T
U3: S4B-PH-SM4-K-TB; CONN-SMD_S4B-PH-SM4-K-TB-LF-SN; MPN S4B-PH-SM4-K-TB(LF)(SN); LCSC Part C265332
U4: LMR33630CRNXR; DigikeyPN LMR33630CRNXR
U5: TLV75533PDRVR; WSON-6_L2.0-W2.0-P0.65-TL-EP; MPN TLV75533PDRVR; LCSC Part C2861750
U6: TCAN1051VDRBRQ1; DigikeyPN TCAN1051VDRBRQ1
U9: USBLC6-2P6; SOT-666; DigikeyPN USBLC6-2SC6_UMW

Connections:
+3V3: C1.1, C2.1, C3.1, C16.1, IC1.1 (VDD5V), IC1.2 (VDD3V3), J5.2, J7.16, J7.18, J7.21, J7.23, J7.26, J8.2, R1.1, R2.1, R3.1, R8.1, R12.1, U1.3 (3V3), U2.15 (VCC_IO), U2.17 (VREF), U5.1 (OUT), U6.5 (VIO)
+5V: C11.1, C17.1, F3.2, L1.2, R5.1, R15.1, R23.1, U5.4 (EN), U5.6 (IN), U6.3 (VCC), U9.5 (VBUS)
/+24V_FUSED: C4.2, C5.1, D6.1 (A), F2.2, Q1.1, Q1.2, Q1.3, TVS1.1 (A1), U2.22 (VS), U2.28 (VS)
/+24V_RAW: F2.1, J3.1, J4.1
/AUX1: J5.3, U1.18 (IO14)
/AUX2: J5.4, U1.17 (IO13)
/BRA: R6.1, U2.23 (BRA)
/BRB: R4.1, U2.27 (BRB)
/BUCK_BST: C9.1, U4.10 (BOOT)
/BUCK_FB: R23.2, R24.2, U4.1 (FB)
/BUCK_SW: C9.2, L1.1, U4.8 (SW), U4.9 (SW)
/CANH: D1.1, J10.1, J11.1, R18.1, U6.7 (CANH)
/CANL: CAN-TERM1.1, D1.2, J10.2, J11.2, U6.6 (CANL)
/CAN_RX: U1.27 (IO47), U6.4 (RXD)
/CAN_STB: U1.33 (IO37), U6.8 (S)
/CAN_TERM_SW: CAN-TERM1.2, R18.2
/CAN_TX: U1.30 (IO48), U6.1 (TXD)
/CPI: C8.1, U2.5 (CPI)
/CPO: C8.2, U2.4 (CPO)
/DIAG: U1.20 (IO16), U2.11 (DIAG)
/DIR: U1.10 (IO6), U2.19 (DIR)
/EN: R12.2, SW7.3, SW7.4, U1.45 (EN)
/GATE_24V: D6.3 (K), Q1.4, R22.1
/INDEX: U1.15 (IO11), U2.12 (INDEX)
/IO0: R1.2, SW8.3, SW8.4, U1.4 (IO0)
/IO46: R11.1, U1.44 (IO46)
/LED1: R17.2, U1.14 (IO10)
/LED2: R13.2, U1.16 (IO12)
/MCU_USB_D_N: U1.23 (USB_D-), U9.6 (I/O1)
/MCU_USB_D_P: U1.24 (USB_D+), U9.4 (I/O2)
/MOTOR_OA1: U2.24 (OA1), U3.1
/MOTOR_OA2: U2.21 (OA2), U3.2
/MOTOR_OB1: U2.26 (OB1), U3.3
/MOTOR_OB2: U2.1 (OB2), U3.4
/NTC_SENSE: NTC1.2, R3.2, U1.11 (IO7)
/SCL: IC1.7 (SCL), J7.15, J8.4, R2.2, U1.13 (IO9)
/SDA: IC1.6 (SDA), J7.14, J8.3, R8.2, U1.12 (IO8)
/STEP: U1.9 (IO5), U2.16 (STEP)
/SW1: SW3.1, U1.31 (IO35)
/SW2: SW1.1, U1.32 (IO36)
/TMC_5VOUT: C6.1, U2.8 (5VOUT)
/TMC_EN: U1.25 (IO21), U2.2 (~EN)
/TMC_RX: R9.2, U1.22 (IO18), U2.14 (~PD/UART)
/TMC_TX: R9.1, U1.21 (IO17)
/USB_CC1: J1.A5 (CC1), R16.1
/USB_CC2: J1.B5 (CC2), R19.1
/USB_D+: J1.A6 (D+), J1.B6 (D+), U9.3 (I/O2)
/USB_D-: J1.A7 (D-), J1.B7 (D-), U9.1 (I/O1)
/USB_LED_LINE: D5.2 (A), R5.2
/USB_VBUS: D7.2 (A), J1.A4 (VBUS), J1.A9 (VBUS), J1.B4 (VBUS), J1.B9 (VBUS)
/USB_VBUS_RAW: D7.1 (K), F3.1
/VBUS_SENSE: R10.1, R15.2, U1.8 (IO4)
/VCC_5V_REG: C10.1, U4.2 (VCC)
/VCP: C4.1, U2.6 (VCP)
GND: C1.2, C2.2, C3.2, C5.2, C6.2, C10.2, C11.2, C12.2, C14.2, C16.2, C17.2, C18.2, CAN-TERM1.4, CAN-TERM1.5, C_BULK1.2, D1.3, D5.1 (K), D8.1 (K), D9.1 (K), IC1.4 (GND), IC1.8 (DIR), J1.A1 (GND), J1.A12 (GND), J1.B1 (GND), J1.B12 (GND), J1.SH (SHIELD), J3.2, J3.S1 (SHIELD1), J3.S2 (SHIELD2), J4.2, J4.S1 (SHIELD1), J4.S2 (SHIELD2), J5.1, J7.1, J7.2, J7.3, J7.7, J7.8, J7.9, J7.10, J7.11, J7.12, J7.13, J7.17, J7.19, J7.20, J7.22, J7.24, J8.1, NTC1.1, R4.2, R6.2, R7.2, R10.2, R11.2, R16.2, R19.2, R22.2, R24.1, SW1.2, SW1.3, SW1.4, SW3.2, SW3.3, SW3.4, SW7.1, SW7.2, SW8.1, SW8.2, TVS1.2 (A2), U1.1 (GND), U1.2 (GND), U1.42 (GND), U1.43 (GND), U1.46 (GND), U1.47 (GND), U1.48 (GND), U1.49 (GND), U1.50 (GND), U1.51 (GND), U1.52 (GND), U1.53 (GND), U1.54 (GND), U1.55 (GND), U1.56 (GND), U1.57 (GND), U1.58 (GND), U1.59 (GND), U1.60 (GND), U1.61 (GND), U1.62 (GND), U1.63 (GND), U1.64 (GND), U1.65 (GND), U2.3 (GND), U2.9 (MS1/AD0), U2.10 (MS2/AD1), U2.13 (CLK), U2.18 (GND), U2.20 (STDBY), U2.29 (GND), U3.5, U3.6, U4.3 (AGND), U4.4 (PGND), U4.12 (EPAD), U5.3 (GND), U5.7 (EP), U6.2 (GND), U6.9 (EPAD), U9.2 (GND); also elsewhere on the board
unnamed: C7.1, J7.30
unnamed: C7.2, J7.29
unnamed: C12.1, J7.5
unnamed: C13.1, J7.28
unnamed: C13.2, J7.27
unnamed: C14.1, J7.4
unnamed: D8.2 (A), R17.1
unnamed: D9.2 (A), R13.1
unnamed: J7.6, R7.1
VIN: C18.1, C_BULK1.1, Q1.5 (D), Q1.6 (D), Q1.7 (D), Q1.8 (D), U4.5 (VIN), U4.6 (VIN), U4.7 (VIN), U4.11 (EN)

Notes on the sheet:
2. TMC2209 STEPPER DRIVER & MOTOR CONNECTOR
5. POWER SUPPLY & 24V POWER INPUT/OUTPUT TERMINALS (VBUS 12-24V -> 5V BUCK -> 3.3V LDO)
6. EXPANSION PORTS & AMPHENOL SFV30R 30-PIN BARE OLED FPC (SSD1306 COG)
1. ESP32-S3 MCU & USB-C PROGRAMMING / DEBUG PORT
4. CAN BUS TRANSCEIVER (SN65HVD230)
3. MT6701 14-BIT MAGNETIC ENCODER

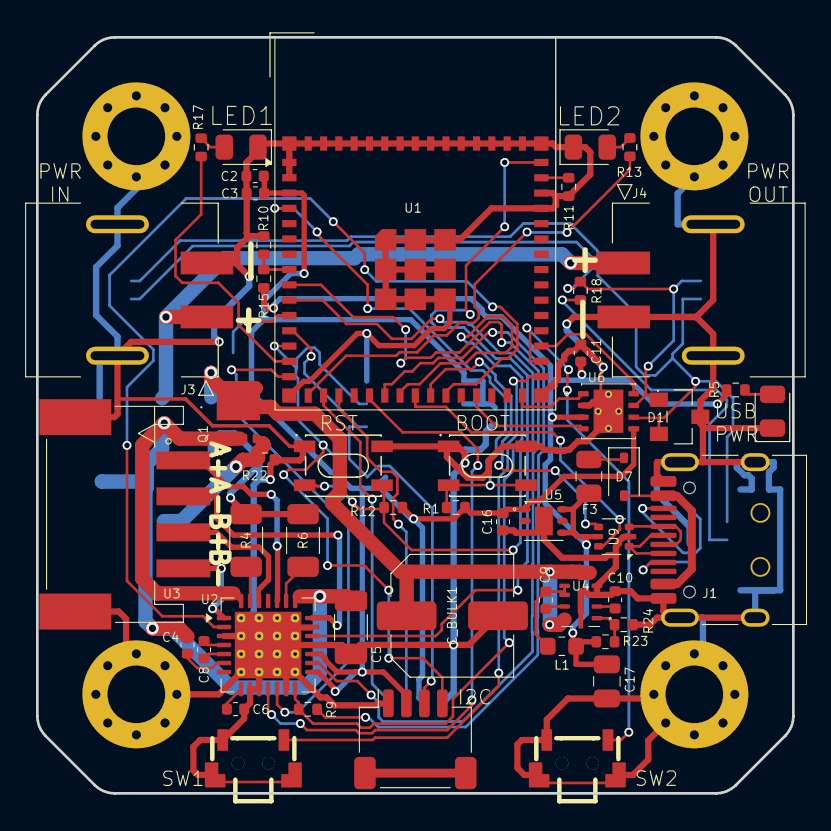
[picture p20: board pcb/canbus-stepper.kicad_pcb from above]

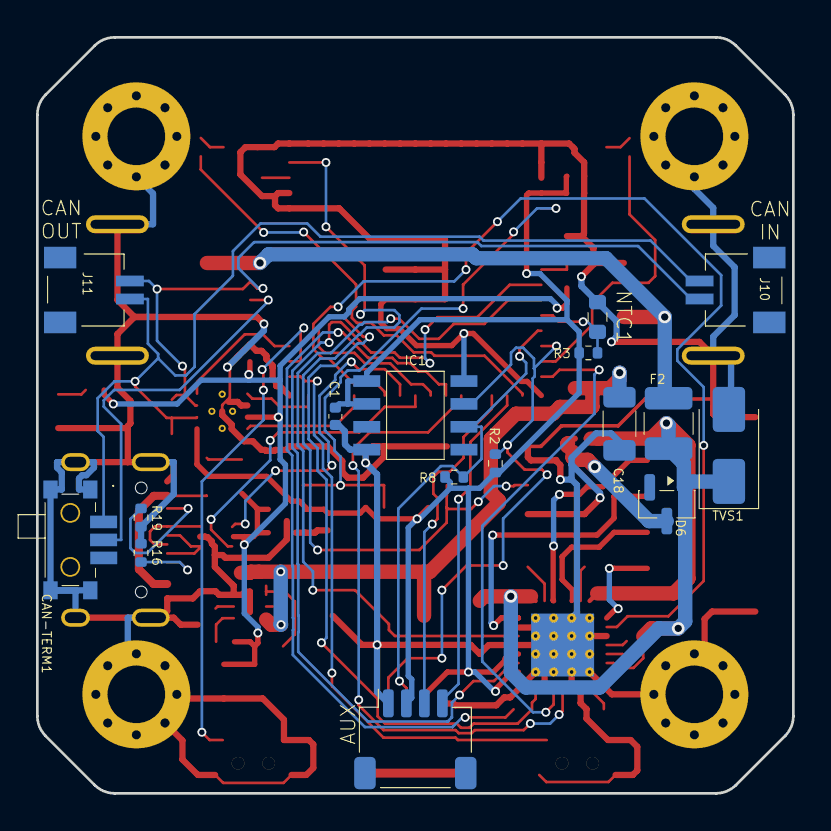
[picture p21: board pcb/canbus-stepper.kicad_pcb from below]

Board: 2 copper layers, 42.0 x 42.0 mm, 67 parts (16 on the bottom side), 58 nets.

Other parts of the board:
BOARD1: NEMA17_PCB_Outline; NEMA17_PCB_Outline_42.0x42.0_8Fillets

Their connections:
GND: BOARD1.H1, BOARD1.H1_V1, BOARD1.H1_V2, BOARD1.H1_V3, BOARD1.H1_V4, BOARD1.H1_V5, BOARD1.H1_V6, BOARD1.H1_V7, BOARD1.H1_V8, BOARD1.H2, BOARD1.H2_V1, BOARD1.H2_V2, BOARD1.H2_V3, BOARD1.H2_V4, BOARD1.H2_V5, BOARD1.H2_V6, BOARD1.H2_V7, BOARD1.H2_V8, BOARD1.H3, BOARD1.H3_V1, BOARD1.H3_V2, BOARD1.H3_V3, BOARD1.H3_V4, BOARD1.H3_V5, BOARD1.H3_V6, BOARD1.H3_V7, BOARD1.H3_V8, BOARD1.H4, BOARD1.H4_V1, BOARD1.H4_V2, BOARD1.H4_V3, BOARD1.H4_V4, BOARD1.H4_V5, BOARD1.H4_V6, BOARD1.H4_V7, BOARD1.H4_V8; also elsewhere on the board

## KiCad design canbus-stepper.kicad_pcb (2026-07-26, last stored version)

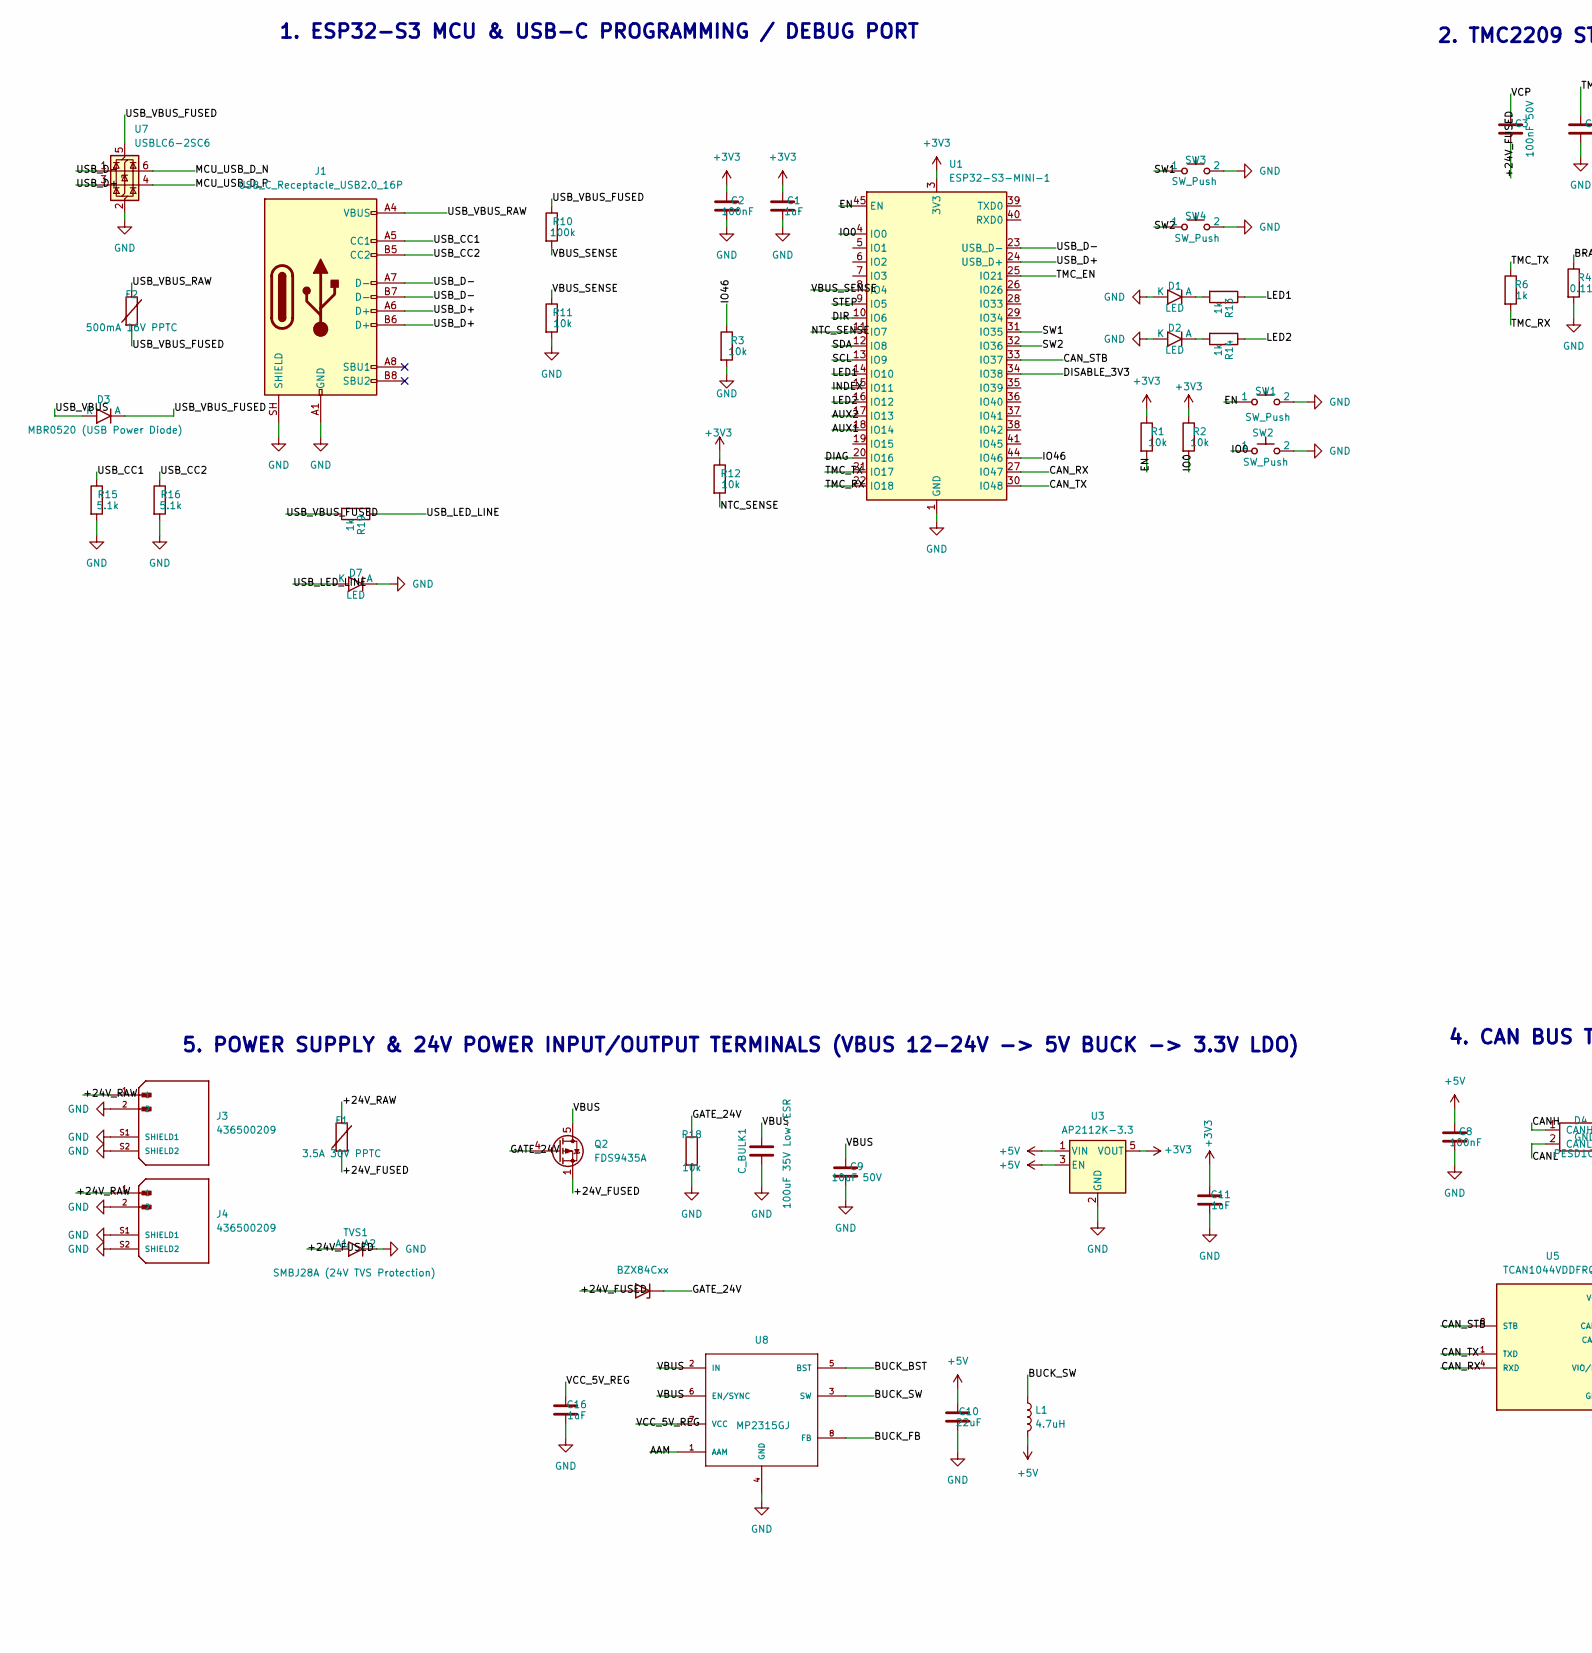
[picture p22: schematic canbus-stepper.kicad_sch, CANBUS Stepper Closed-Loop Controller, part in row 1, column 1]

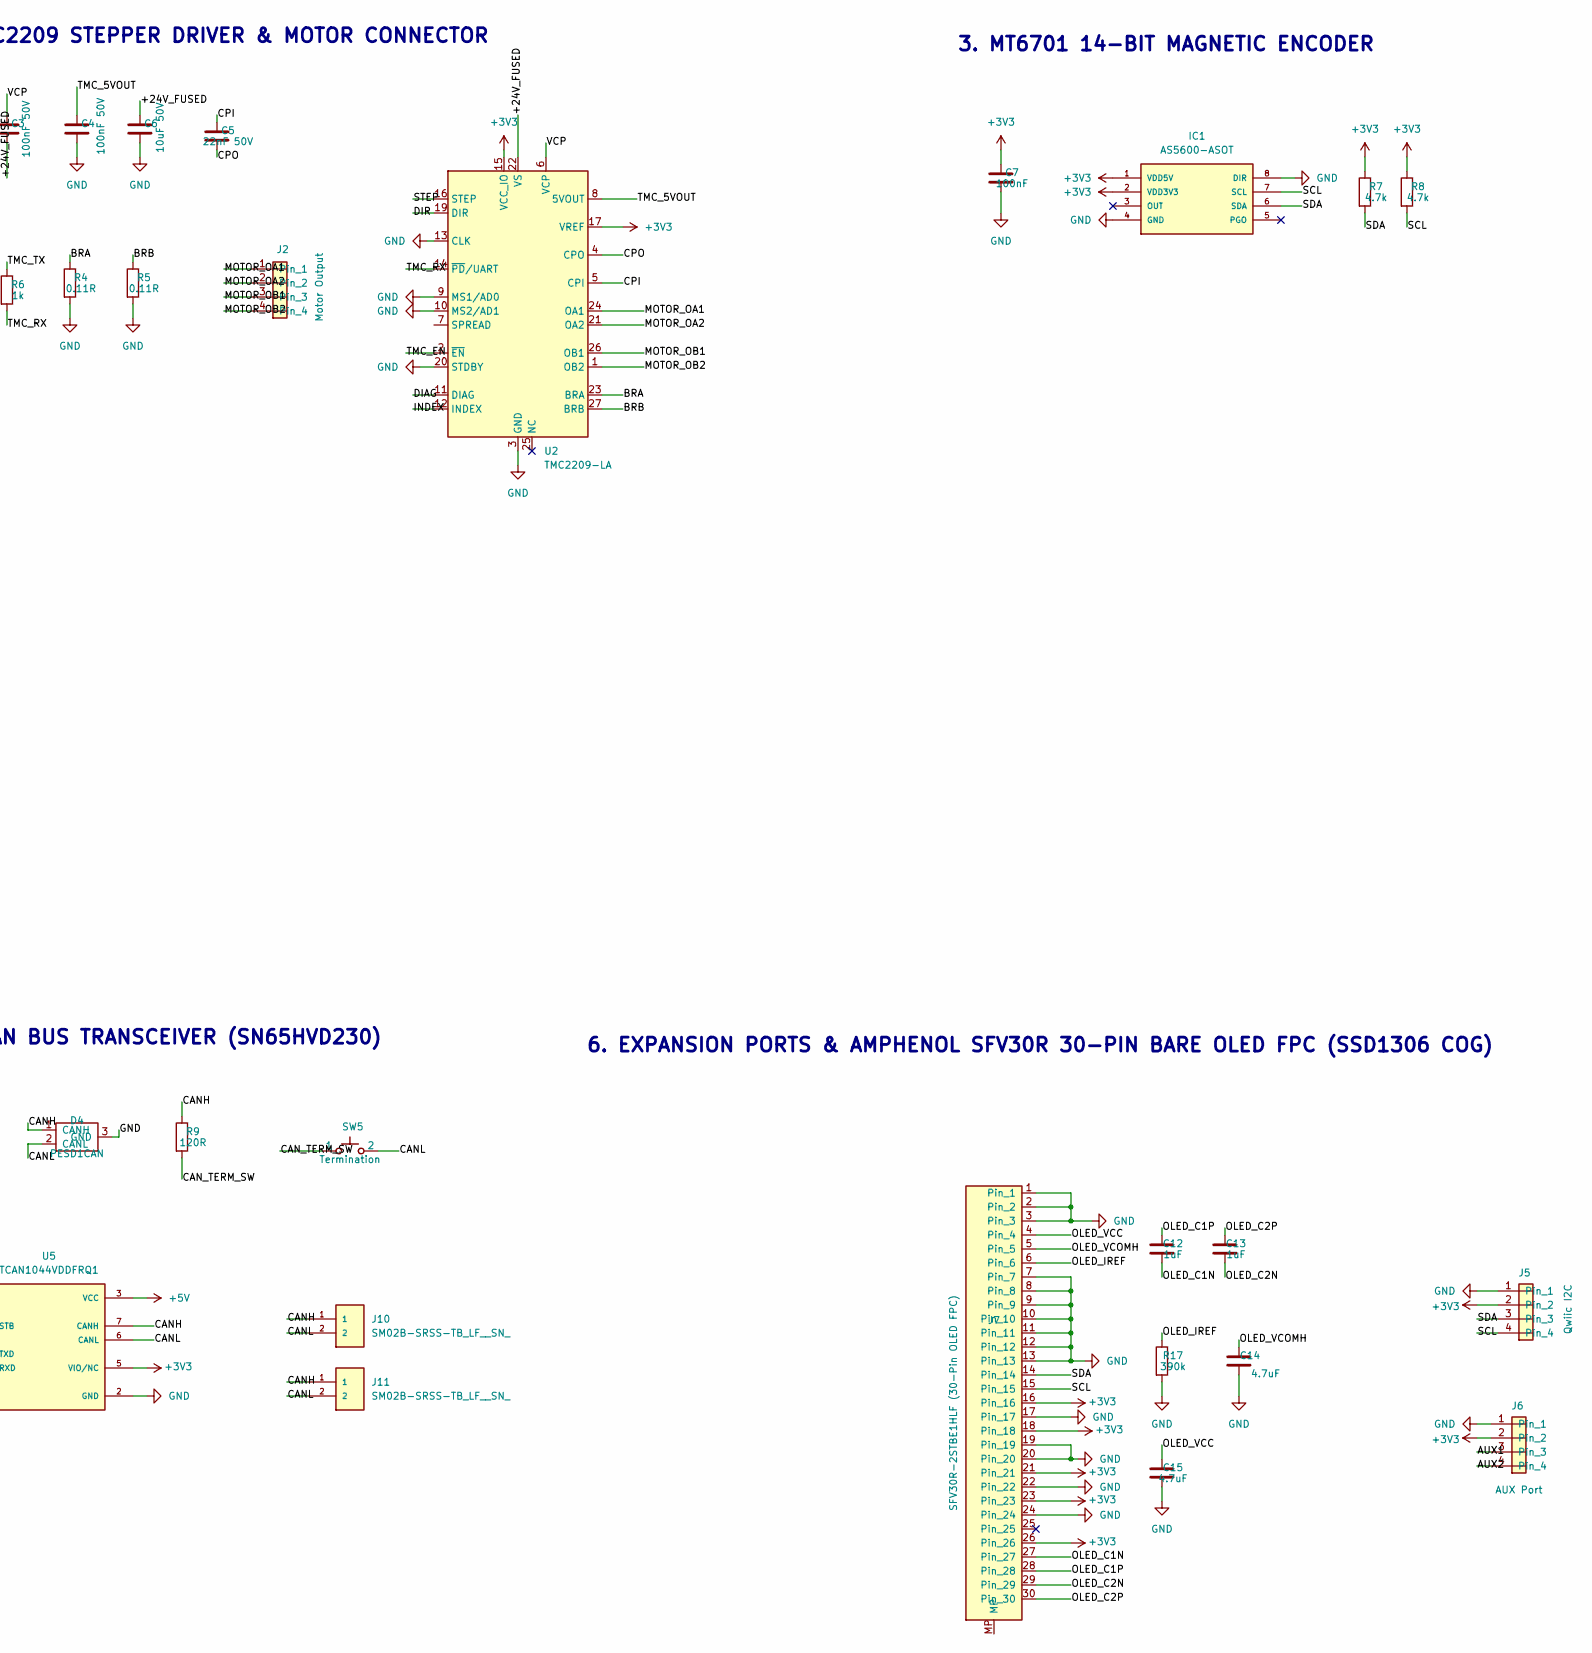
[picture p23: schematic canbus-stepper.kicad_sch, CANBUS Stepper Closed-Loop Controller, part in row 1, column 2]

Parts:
C1, C11, C12, C13: 1uF; C_0603_1608Metric
C2, C7, C8: 100nF; C_0603_1608Metric
C3, C4: 100nF 50V; C_0603_1608Metric
C5: 22nF 50V; C_0603_1608Metric
C6, C9: 10uF 50V; C_1206_3216Metric
C10: 22uF; C_0805_2012Metric
C14, C15: 4.7uF; C_0603_1608Metric
C16: 1uF; C_0805_2012Metric
C_BULK1: 100uF 35V Low-ESR; CP_Elec_6.3x5.8
D1, D2, D7: LED; LED_0805_2012Metric
D3: MBR0520 (USB Power Diode); D_SOD-123
D4: PESD1CAN; SOT-23; LCSC PESD1CAN
D6: BZX84Cxx; SOT-23
F1: 3.5A 30V PPTC; Fuse_1812_4532Metric
F2: 500mA 16V PPTC; Fuse_0805_2012Metric
IC1: AS5600-ASOT; MOUSER_PART_NUMBER 985-AS5600-ASOT
J1: USB_C_Receptacle_USB2.0_16P; USB_C_Receptacle_16P; LCSC UJ20-C-H-G-SMT-4-P16-TR
J2: Motor Output; JST_S4B-PH-SM4-TB; LCSC S4B-PH-SM4-TB
J3: 436500209; MOLEX_436500209; PARTREV E2; LCSC 0436500209
J4: 436500209; MOLEX_436500209; PARTREV E2
J5: Qwiic I2C; JST_SH_SM04B-SRSS-TB_1x04-1MP_P1.00mm_Horizontal
J6: AUX Port; JST_SH_SM04B-SRSS-TB_1x04-1MP_P1.00mm_Horizontal
J7: SFV30R-2STBE1HLF (30-Pin OLED FPC); AMPHENOL_SFV30R-2STBE1HLF; LCSC SFV30R-2STBE1HLF
J10, J11: SM02B-SRSS-TB_LF__SN_; LCSC SM02B-SRSS-TB
L1: 4.7uH; L_0603_1608Metric
Q2: FDS9435A; SOIC-8_3.9x4.9mm_P1.27mm; LCSC AO4407A
R1, R2, R3, R11, R12, R18: 10k; R_0603_1608Metric
R4, R5: 0.11R; R_1206_3216Metric
R6, R13, R14, R19: 1k; R_0603_1608Metric
R7, R8: 4.7k; R_0603_1608Metric
R9: 120R; R_0603_1608Metric
R10: 100k; R_0603_1608Metric
R15, R16: 5.1k; R_0603_1608Metric
R17: 390k; R_0603_1608Metric
SW1, SW2: SW_Push; SW_TL3365AF180QG; LCSC TL3365AF180QG
SW3, SW4: SW_Push; SW_TS31-46-35-BK-B-160-RA-SMT-TR; LCSC TS31-46-35-BK-B-160-RA-SMT-TR
SW5: Termination; SW_DIP_SPSTx01_Slide_Copal_CHS-01A_W5.08mm_P1.27mm_JPin
TVS1: SMBJ28A (24V TVS Protection); D_SMB
U1: ESP32-S3-MINI-1; ESP32-S2-MINI-1; LCSC ESP32-S3-MINI-1-N4R2
U2: TMC2209-LA; VQFN-28-1EP_5x5mm_P0.5mm_EP3.7x3.7mm_ThermalVias; LCSC TMC2209-LA
U3: AP2112K-3.3; SOT-23-5; LCSC AP2112K-3.3TRG1
U5: TCAN1044VDDFRQ1; SOT65P280X110-8N; PARTREV C; LCSC TCAN1044VDDFR
U7: USBLC6-2SC6; SOT-23-6; LCSC USBLC6-2SC6_UMW
U8: MP2315GJ; SOT-23-8; MPN MP2315

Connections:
+3V3: C1.1, C2.1, C7.1, C11.1, IC1.1 (VDD5V), IC1.2 (VDD3V3), J5.2, J6.2, J7.16, J7.18, J7.21, J7.23, J7.26, R1.1, R2.1, R7.1, R8.1, R12.1, U1.3 (3V3), U2.15 (VCC_IO), U2.17 (VREF), U3.5 (VOUT), U5.5 (VIO/NC)
+5V: C8.1, C10.1, L1.2, U3.1 (VIN), U3.3 (EN), U5.3 (VCC)
/+24V_FUSED: C3.2, C6.1, D6.1 (A), F1.2, Q2.1 (S), Q2.2 (S), Q2.3 (S), TVS1.1 (A1), U2.22 (VS), U2.28 (VS)
/+24V_RAW: F1.1, J3.1, J4.1
/AAM: U8.1 (AAM)
/AUX1: J6.3, U1.18 (IO14)
/AUX2: J6.4, U1.17 (IO13)
/BRA: R4.1, U2.23 (BRA)
/BRB: R5.1, U2.27 (BRB)
/BUCK_BST: U8.5 (BST)
/BUCK_FB: U8.8 (FB)
/BUCK_SW: L1.1, U8.3 (SW)
/CANH: D4.1 (CANH), J10.1, J11.1, R9.1, U5.7 (CANH)
/CANL: D4.2 (CANL), J10.2, J11.2, SW5.2, U5.6 (CANL)
/CAN_RX: U1.27 (IO47), U5.4 (RXD)
/CAN_STB: U1.33 (IO37), U5.8 (STB)
/CAN_TERM_SW: R9.2, SW5.1
/CAN_TX: U1.30 (IO48), U5.1 (TXD)
/CPI: C5.1, U2.5 (CPI)
/CPO: C5.2, U2.4 (CPO)
/DIAG: U1.20 (IO16), U2.11 (DIAG)
/DIR: U1.10 (IO6), U2.19 (DIR)
/DISABLE_3V3: U1.34 (IO38)
/EN: R1.2, SW1.1, U1.45 (EN)
/GATE_24V: D6.3 (K), Q2.4 (G), R18.1
/INDEX: U1.15 (IO11), U2.12 (INDEX)
/IO0: R2.2, SW2.1, U1.4 (IO0)
/IO46: R3.1, U1.44 (IO46)
/LED1: R13.1, U1.14 (IO10)
/LED2: R14.1, U1.16 (IO12)
/MCU_USB_D_N: U7.6 (I/O1)
/MCU_USB_D_P: U7.4 (I/O2)
/MOTOR_OA1: J2.1, U2.24 (OA1)
/MOTOR_OA2: J2.2, U2.21 (OA2)
/MOTOR_OB1: J2.3, U2.26 (OB1)
/MOTOR_OB2: J2.4, U2.1 (OB2)
/NTC_SENSE: R12.2, U1.11 (IO7)
/OLED_C1N: C12.2, J7.27
/OLED_C1P: C12.1, J7.28
/OLED_C2N: C13.2, J7.29
/OLED_C2P: C13.1, J7.30
/OLED_IREF: J7.6, R17.1
/OLED_VCC: C15.1, J7.4
/OLED_VCOMH: C14.1, J7.5
/SCL: IC1.7 (SCL), J5.4, J7.15, R8.2, U1.13 (IO9)
/SDA: IC1.6 (SDA), J5.3, J7.14, R7.2, U1.12 (IO8)
/STEP: U1.9 (IO5), U2.16 (STEP)
/SW1: SW3.1, U1.31 (IO35)
/SW2: SW4.1, U1.32 (IO36)
/TMC_5VOUT: C4.1, U2.8 (5VOUT)
/TMC_EN: U1.25 (IO21), U2.2 (~EN)
/TMC_RX: R6.2, U1.22 (IO18), U2.14 (~PD/UART)
/TMC_TX: R6.1, U1.21 (IO17)
/USB_CC1: J1.A5 (CC1), R15.1
/USB_CC2: J1.B5 (CC2), R16.1
/USB_D+: J1.A6 (D+), J1.B6 (D+), U1.24 (USB_D+), U7.3 (I/O2)
/USB_D-: J1.A7 (D-), J1.B7 (D-), U1.23 (USB_D-), U7.1 (I/O1)
/USB_LED_LINE: D7.1 (K), R19.1
/USB_VBUS: D3.1 (K)
/USB_VBUS_FUSED: D3.2 (A), F2.2, R10.1, R19.2, U7.5 (VBUS)
/USB_VBUS_RAW: F2.1, J1.A4 (VBUS), J1.A9 (VBUS), J1.B4 (VBUS), J1.B9 (VBUS)
/VBUS: C9.1, C_BULK1.1, Q2.5 (D), Q2.6 (D), Q2.7 (D), Q2.8 (D), U8.2 (IN), U8.6 (EN/SYNC)
/VBUS_SENSE: R10.2, R11.1, U1.8 (IO4)
/VCC_5V_REG: C16.1, U8.7 (VCC)
/VCP: C3.1, U2.6 (VCP)
GND: C1.2, C2.2, C4.2, C6.2, C7.2, C8.2, C9.2, C10.2, C11.2, C14.2, C15.2, C16.2, C_BULK1.2, D1.1 (K), D2.1 (K), D4.3 (GND), D7.2 (A), IC1.4 (GND), IC1.8 (DIR), J1.A1 (GND), J1.A12 (GND), J1.B1 (GND), J1.B12 (GND), J1.SH (SHIELD), J3.2, J3.S1 (SHIELD1), J3.S2 (SHIELD2), J4.2, J4.S1 (SHIELD1), J4.S2 (SHIELD2), J5.1, J6.1, J7.1, J7.2, J7.3, J7.7, J7.8, J7.9, J7.10, J7.11, J7.12, J7.13, J7.17, J7.19, J7.20, J7.22, J7.24, R3.2, R4.2, R5.2, R11.2, R15.2, R16.2, R17.2, R18.2, SW1.2, SW2.2, SW3.2, SW4.2, TVS1.2 (A2), U1.1 (GND), U1.2 (GND), U1.42 (GND), U1.43 (GND), U1.46 (GND), U1.47 (GND), U1.48 (GND), U1.49 (GND), U1.50 (GND), U1.51 (GND), U1.52 (GND), U1.53 (GND), U1.54 (GND), U1.55 (GND), U1.56 (GND), U1.57 (GND), U1.58 (GND), U1.59 (GND), U1.60 (GND), U1.61 (GND), U1.62 (GND), U1.63 (GND), U1.64 (GND), U1.65 (GND), U2.3 (GND), U2.9 (MS1/AD0), U2.10 (MS2/AD1), U2.13 (CLK), U2.18 (GND), U2.20 (STDBY), U2.29 (GND), U3.2 (GND), U5.2 (GND), U7.2 (GND), U8.4 (GND); also elsewhere on the board
unnamed: D1.2 (A), R13.2
unnamed: D2.2 (A), R14.2

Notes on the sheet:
2. TMC2209 STEPPER DRIVER & MOTOR CONNECTOR
5. POWER SUPPLY & 24V POWER INPUT/OUTPUT TERMINALS (VBUS 12-24V -> 5V BUCK -> 3.3V LDO)
6. EXPANSION PORTS & AMPHENOL SFV30R 30-PIN BARE OLED FPC (SSD1306 COG)
1. ESP32-S3 MCU & USB-C PROGRAMMING / DEBUG PORT
4. CAN BUS TRANSCEIVER (SN65HVD230)
3. MT6701 14-BIT MAGNETIC ENCODER

Board: 2 copper layers, 69 parts (11 on the bottom side), 61 nets, no tracks yet.

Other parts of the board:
BOARD1: NEMA17_PCB_Outline; NEMA17_PCB_Outline_40.3x40.3_8Fillets

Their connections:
GND: BOARD1.H1, BOARD1.H1_V1, BOARD1.H1_V2, BOARD1.H1_V3, BOARD1.H1_V4, BOARD1.H1_V5, BOARD1.H1_V6, BOARD1.H1_V7, BOARD1.H1_V8, BOARD1.H2, BOARD1.H2_V1, BOARD1.H2_V2, BOARD1.H2_V3, BOARD1.H2_V4, BOARD1.H2_V5, BOARD1.H2_V6, BOARD1.H2_V7, BOARD1.H2_V8, BOARD1.H3, BOARD1.H3_V1, BOARD1.H3_V2, BOARD1.H3_V3, BOARD1.H3_V4, BOARD1.H3_V5, BOARD1.H3_V6, BOARD1.H3_V7, BOARD1.H3_V8, BOARD1.H4, BOARD1.H4_V1, BOARD1.H4_V2, BOARD1.H4_V3, BOARD1.H4_V4, BOARD1.H4_V5, BOARD1.H4_V6, BOARD1.H4_V7, BOARD1.H4_V8; also elsewhere on the board

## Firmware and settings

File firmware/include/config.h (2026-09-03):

#pragma once

#include <Arduino.h>

// =============================================================================
// CANBUS-Stepper v1.1 Hardware Configuration & Pinout Map
// =============================================================================

// --- TMC2209-LA Stepper Driver Pins ---
#define PIN_TMC_STEP        33  // Step pulse input (IO33 / Pad 28)
#define PIN_TMC_DIR         34  // Direction control (IO34 / Pad 29)
#define PIN_TMC_EN          48  // Driver Enable (Active LOW) (IO48 / Pad 30)
#define PIN_TMC_TX          35  // ESP32 TX -> TMC2209 RX (UART) (IO35 / Pad 31)
#define PIN_TMC_RX          47  // ESP32 RX <- TMC2209 TX (UART) (IO47 / Pad 27)
#define PIN_TMC_DIAG        21  // StallGuard / Fault interrupt (IO21 / Pad 25)
#define PIN_TMC_INDEX       26  // Microstep index output (IO26 / Pad 26)

#define TMC_SERIAL_PORT     Serial1
#define TMC_BAUDRATE        115200
#define TMC_R_SENSE         0.11f  // 0.11 Ohm sense resistors (R4, R6 in schematic)
#define TMC_DRIVER_ADDRESS  0b00   // MS1=0, MS2=0 address

// --- AMS AS5600 12-Bit Magnetic Rotary Encoder ---
#define PIN_I2C_SDA         16  // Hardware I2C SDA (IO16 / Pad 20)
#define PIN_I2C_SCL         14  // Hardware I2C SCL (IO14 / Pad 18)
#define I2C_FREQUENCY       400000 // 400 kHz Fast-mode I2C
#define AS5600_I2C_ADDR     0x36

#define ENCODER_RESOLUTION  4096   // 12-bit (0 - 4095)
#define DEG_PER_COUNT       (360.0f / 4096.0f) // 0.08789 degrees per count

// --- CAN Bus / TWAI Transceiver (TI TCAN3413) ---
#define PIN_CAN_TX          38  // ESP32 TWAI TX (IO38 / Pad 34)
#define PIN_CAN_RX          37  // ESP32 TWAI RX (IO37 / Pad 33)
#define PIN_CAN_STB         39  // Standby pin (LOW = Normal Mode, HIGH = Standby) (IO39 / Pad 35)
#define DEFAULT_CAN_BAUD    500000 // 500 kbps default CAN baudrate (supports up to 1Mbps)
#define DEFAULT_CAN_NODE_ID 0x120  // Default Node ID for actuator

// --- Analog Sensing (ADC1) ---
#define PIN_VBUS_SENSE      2   // 24V/VBUS Voltage divider input (ADC1_CH1 / IO2 / Pad 6)
#define PIN_NTC_SENSE       3   // On-board / Motor NTC Thermistor (ADC1_CH2 / IO3 / Pad 7)

#define VBUS_R_TOP          100000.0f // 100k Ohm top divider (R20)
#define VBUS_R_BOTTOM       10000.0f  // 10k Ohm bottom divider (R14)
#define VBUS_DIVIDER_RATIO  ((VBUS_R_TOP + VBUS_R_BOTTOM) / VBUS_R_BOTTOM) // 11.0x

#define NTC_R_SERIES        10000.0f  // 10k series pull-up resistor (R3)
#define NTC_NOMINAL_R       100000.0f // 100k nominal resistance at 25C (NCU18WF104)
#define NTC_NOMINAL_TEMP    25.0f     // 25 °C
#define NTC_B_COEFFICIENT   4250.0f   // Beta coefficient (B25/50)

// --- User Controls & Status Indicators ---
#define PIN_LED1            1   // Status LED 1 (Heartbeat / Activity) (IO1 / Pad 5)
#define PIN_LED2            45  // Status LED 2 (CAN Activity / Warning) (IO45 / Pad 41)
#define PIN_SW1             6   // Tactile Switch 1 (User / Mode Select) (IO6 / Pad 10)
#define PIN_SW2             36  // Tactile Switch 2 (Calibrate / E-Stop) (IO36 / Pad 32)

// --- Expansion & Auxiliary GPIOs ---
#define PIN_AUX1            4   // AUX Header GPIO 1 / Endstop 1 (IO4 / Pad 8)
#define PIN_AUX2            5   // AUX Header GPIO 2 / Endstop 2 (IO5 / Pad 9)

// --- Motion & PID Default Parameters ---
#define DEFAULT_MICROSTEPS  16
#define STEPS_PER_REV_NEMA  (200 * DEFAULT_MICROSTEPS) // 3200 steps/rev for 1.8 deg motor
#define DEFAULT_MAX_VELOCITY 50000.0f // steps/s
#define DEFAULT_ACCEL       100000.0f // steps/s^2

#define PID_KP              2.5f
#define PID_KI              0.05f
#define PID_KD              0.12f
#define PID_LOOP_HZ         1000  // 1 kHz Closed-Loop Control Frequency

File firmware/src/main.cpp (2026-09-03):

#include <Arduino.h>
#include "config.h"
#include "modes.h"
#include "encoder_as5600.h"
#include "ntc_sensor.h"
#include "tmc2209_handler.h"
#include "motion_controller.h"
#include "can_protocol.h"
#include "microros_handler.h"

// --- Global Hardware Objects ---
EncoderAS5600 encoder;
PowerAndThermalMonitor monitor;
TMC2209Handler driver;
MotionController motion(driver, encoder);
CANBusProtocol can_bus(motion, encoder, monitor, driver);
MicroROSHandler ros_node(motion, encoder, monitor);

// --- Task & State Variables ---
TaskHandle_t motionTaskHandle = NULL;
uint32_t last_heartbeat_ms = 0;
uint32_t last_diag_log_ms = 0;
bool led_state = false;

// --- High Priority Motion & PID Control Task (Core 1) ---
void motionControlTask(void *pvParameters) {
    TickType_t xLastWakeTime = xTaskGetTickCount();
    const TickType_t xFrequency = pdMS_TO_TICKS(1); // 1 ms = 1000 Hz loop

    for (;;) {
        motion.update();
        vTaskDelayUntil(&xLastWakeTime, xFrequency);
    }
}

// --- Interactive Serial Console Parser ---
void handleSerialCommands() {
    if (Serial.available() > 0) {
        String cmd = Serial.readStringUntil('\n');
        cmd.trim();

        if (cmd.startsWith("P ")) {
            float pos = cmd.substring(2).toFloat();
            motion.setTargetPosition(pos);
            motion.setControlMode(ControlMode::CLOSED_LOOP_POSITION);
            Serial.printf("[CMD] Target Position set to: %.2f deg\n", pos);
        } else if (cmd.startsWith("V ")) {
            float vel = cmd.substring(2).toFloat();
            motion.setTargetVelocity(vel);
            motion.setControlMode(ControlMode::CLOSED_LOOP_VELOCITY);
            Serial.printf("[CMD] Target Velocity set to: %.2f deg/s\n", vel);
        } else if (cmd.equalsIgnoreCase("EN")) {
            motion.enable(true);
            Serial.println("[CMD] Motor Enabled (Closed Loop)");
        } else if (cmd.equalsIgnoreCase("DIS")) {
            motion.enable(false);
            Serial.println("[CMD] Motor Disabled");
        } else if (cmd.equalsIgnoreCase("ZERO")) {
            encoder.setZeroPosition();
            motion.setTargetPosition(0.0f);
            Serial.println("[CMD] Zero position calibrated");
        } else if (cmd.startsWith("CUR ")) {
            uint16_t ma = (uint16_t)cmd.substring(4).toInt();
            driver.setCurrent(ma);
            Serial.printf("[CMD] Motor Current set to: %d mA\n", ma);
        } else if (cmd.startsWith("PID ")) {
            // PID <kp> <ki> <kd>
            float kp, ki, kd;
            if (sscanf(cmd.c_str(), "PID %f %f %f", &kp, &ki, &kd) == 3) {
                motion.setPIDGains(kp, ki, kd);
                Serial.printf("[CMD] PID Gains set: Kp=%.2f, Ki=%.3f, Kd=%.3f\n", kp, ki, kd);
            }
        } else if (cmd.equalsIgnoreCase("STATUS") || cmd.equalsIgnoreCase("?")) {
            Serial.println("\n========== CANBUS-Stepper v1.1 Status ==========");
            Serial.printf("Encoder Angle: %.2f deg (Raw: %d, Turns: %d)\n", 
                          encoder.getAngleDegrees(), encoder.getRawAngle(), encoder.getMultiTurnAngle() / 4096);
            Serial.printf("Target Position: %.2f deg | Error: %.2f deg\n", 
                          motion.getTargetPosition(), motion.getPositionError());
            Serial.printf("Velocity: %.2f deg/s\n", encoder.getVelocityDegPerSec());
            Serial.printf("VBUS Voltage: %.2f V | Temperature: %.1f C\n", 
                          monitor.getVbusVoltage(), monitor.getTemperatureC());
            Serial.printf("CAN Bus: %s (RX: %d, TX: %d)\n", 
                          can_bus.isBusHealthy() ? "HEALTHY" : "ERROR/OFFLINE", can_bus.getRxCount(), can_bus.getTxCount());
            AS5600Status s = encoder.getStatus();
            Serial.printf("Magnet: %s (Gain AGC: %d, Magnitude: %d)\n", 
                          s.magnet_detected ? "DETECTED" : "MISSING", s.gain_agc, s.magnitude);
            Serial.println("================================================\n");
        }
    }
}

void setup() {
    // 1. Initialize USB CDC Serial
    Serial.begin(115200);
    delay(500);

    Serial.println("\n=======================================================");
    Serial.println("⚡ CANBUS-Stepper v1.1 Smart Closed-Loop Controller");
    Serial.println("   ESP32-S3 + TMC2209 + AS5600 + TCAN3413");
    Serial.println("=======================================================");

    // 2. Setup User GPIOs
    pinMode(PIN_LED1, OUTPUT);
    pinMode(PIN_LED2, OUTPUT);
    pinMode(PIN_SW1, INPUT_PULLUP);
    pinMode(PIN_SW2, INPUT_PULLUP);
    pinMode(PIN_AUX1, INPUT_PULLUP);
    pinMode(PIN_AUX2, INPUT_PULLUP);

    digitalWrite(PIN_LED1, HIGH);
    digitalWrite(PIN_LED2, LOW);

    // 3. Initialize ADC Power & Temperature Monitor
    monitor.begin();
    Serial.printf("[INIT] VBUS Voltage: %.2fV | Board Temp: %.1fC\n", monitor.getVbusVoltage(), monitor.getTemperatureC());

    // 4. Initialize AS5600 Magnetic Rotary Encoder
    bool enc_ok = encoder.begin();
    if (enc_ok) {
        Serial.printf("[INIT] AS5600 Encoder: OK (Angle: %.2f deg)\n", encoder.getAngleDegrees());
    } else {
        Serial.println("[INIT] AS5600 Encoder: WARNING - Magnet not detected!");
    }

    // 5. Initialize TMC2209 Stepper Driver
    bool tmc_ok = driver.begin();
    if (tmc_ok) {
        Serial.println("[INIT] TMC2209 Stepper Driver: OK (UART Connected)");
    } else {
        Serial.println("[INIT] TMC2209 Stepper Driver: UART not responding (will run in standalone STEP/DIR mode)");
    }

    // 6. Initialize Motion Controller
    motion.begin();
    Serial.println("[INIT] Closed-Loop Motion Controller Initialized");

    // 7. Initialize TWAI CAN Bus Protocol
    bool can_ok = can_bus.begin(DEFAULT_CAN_BAUD, DEFAULT_CAN_NODE_ID);
    if (can_ok) {
        Serial.printf("[INIT] TCAN3413 CAN Bus: RUNNING @ %d bps (Node ID: 0x%X)\n", DEFAULT_CAN_BAUD, DEFAULT_CAN_NODE_ID);
    } else {
        Serial.println("[INIT] TCAN3413 CAN Bus: Failed to start TWAI driver");
    }

    // 8. Launch High-Priority Motion Control Task on Core 1
    xTaskCreatePinnedToCore(
        motionControlTask,
        "MotionTask",
        4096,
        NULL,
        configMAX_PRIORITIES - 1, // Highest priority
        &motionTaskHandle,
        1 // Core 1
    );

    Serial.println("[INIT] System Ready! Type '?' or 'STATUS' for telemetry.\n");
}

void loop() {
    // 1. Update CAN Bus Protocol & process incoming frames
    can_bus.update();

    // 2. Update ADC monitoring (VBUS & Temperature)
    monitor.update();

    // 3. Safety Thermal & Undervoltage Interlocks
    if (monitor.isOverheated(90.0f)) {
        motion.emergencyStop();
        digitalWrite(PIN_LED2, HIGH);
        Serial.println("[ALERT] EMERGENCY STOP: Overtemperature detected!");
    }

    // 4. Handle Hardware User Buttons
    if (digitalRead(PIN_SW2) == LOW) { // E-Stop button
        motion.emergencyStop();
        delay(200);
    }
    if (digitalRead(PIN_SW1) == LOW) { // Zero calibration button
        encoder.setZeroPosition();
        motion.setTargetPosition(0.0f);
        delay(200);
    }

    // 5. Handle Serial CLI input
    handleSerialCommands();

    // 6. Heartbeat LED blink (1 Hz)
    uint32_t now_ms = millis();
    if (now_ms - last_heartbeat_ms >= 500) {
        last_heartbeat_ms = now_ms;
        led_state = !led_state;
        digitalWrite(PIN_LED1, led_state ? HIGH : LOW);

        // Flash CAN LED if bus has activity
        if (can_bus.getRxCount() > 0) {
            digitalWrite(PIN_LED2, (can_bus.getRxCount() % 2 == 0) ? HIGH : LOW);
        }
    }

    vTaskDelay(pdMS_TO_TICKS(5));
}

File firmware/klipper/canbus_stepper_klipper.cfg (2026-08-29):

# =========================================================================
# CANBUS-Stepper v1.1 Klipper Configuration Template
# ESP32-S3 Closed-Loop Stepper & Toolhead CAN Node
# =========================================================================

[mcu can_stepper]
canbus_uuid: <YOUR_CANBUS_UUID>
# Run `~/klippy-env/bin/python ~/klipper/scripts/canbus_query.py can0` to find UUID

# -------------------------------------------------------------------------
# Motor Configuration (Example: Extruder / Toolhead / Actuator Axis)
# -------------------------------------------------------------------------
[extruder]
step_pin: can_stepper:gpio33
dir_pin: !can_stepper:gpio34
enable_pin: !can_stepper:gpio48
microsteps: 16
rotation_distance: 22.68
nozzle_diameter: 0.400
filament_diameter: 1.750
heater_pin: PA0 # (Configure if using external hotend board or toolhead expansion)
sensor_type: EPCOS 100K B57560G104F
sensor_pin: can_stepper:gpio3 # On-board / Extruder NTC thermistor input (ADC1_CH2)
control: pid
pid_Kp: 22.2
pid_Ki: 1.08
pid_Kd: 114
min_temp: 0
max_temp: 300

# -------------------------------------------------------------------------
# Trinamic TMC2209 UART Configuration
# -------------------------------------------------------------------------
[tmc2209 extruder]
uart_pin: can_stepper:gpio47
tx_pin: can_stepper:gpio35
uart_address: 0
run_current: 0.700
stealthchop_threshold: 999999
interpolate: true
sense_resistor: 0.110
diag_pin: ^can_stepper:gpio21 # TMC DIAG pin (StallGuard4)
driver_SGTHRS: 100

# -------------------------------------------------------------------------
# Board Temperature & Voltage Monitoring
# -------------------------------------------------------------------------
[temperature_sensor can_stepper_temp]
sensor_type: Generic 3950
sensor_pin: can_stepper:gpio3
min_temp: -10
max_temp: 110

# -------------------------------------------------------------------------
# Auxiliary Endstops / Bed Probe Inputs
# -------------------------------------------------------------------------
[probe]
pin: ^can_stepper:gpio4 # AUX1 Port
x_offset: 0.0
y_offset: 25.0
z_offset: 0.0
speed: 5.0

# [filament_switch_sensor runout]
# switch_pin: ^can_stepper:gpio5 # AUX2 Port
# pause_on_runout: True

# -------------------------------------------------------------------------
# Status LEDs
# -------------------------------------------------------------------------
[output_pin status_led]
pin: can_stepper:gpio1
value: 1
shutdown_value: 0

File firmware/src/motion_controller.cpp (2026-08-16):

#include "motion_controller.h"
#include <math.h>

MotionController::MotionController(TMC2209Handler &driver, EncoderAS5600 &encoder)
    : _driver(driver),
      _encoder(encoder),
      _control_mode(ControlMode::MOTOR_DISABLED),
      _target_pos_deg(0.0f),
      _target_vel_deg_s(0.0f),
      _current_setpoint_deg(0.0f),
      _integral_error(0.0f),
      _last_error(0.0f),
      _last_measured_pos(0.0f),
      _last_loop_us(0),
      _step_count(0),
      _direction(1) {
    _pid.kp = PID_KP;
    _pid.ki = PID_KI;
    _pid.kd = PID_KD;
    _pid.max_integral = 500.0f;
    _pid.max_output = 3600.0f; // Max deg/s output velocity
}

void MotionController::begin() {
    pinMode(PIN_TMC_STEP, OUTPUT);
    pinMode(PIN_TMC_DIR, OUTPUT);
    digitalWrite(PIN_TMC_STEP, LOW);
    digitalWrite(PIN_TMC_DIR, LOW);

    _last_loop_us = micros();
    _last_measured_pos = _encoder.getMultiTurnAngle() * DEG_PER_COUNT;
    _target_pos_deg = _last_measured_pos;
    _current_setpoint_deg = _last_measured_pos;
}

void MotionController::setControlMode(ControlMode mode) {
    _control_mode = mode;
    _integral_error = 0.0f;
    _last_error = 0.0f;
    if (mode == ControlMode::MOTOR_DISABLED) {
        _driver.enable(false);
    } else {
        _driver.enable(true);
    }
}

void MotionController::setTargetPosition(float target_deg) {
    _target_pos_deg = target_deg;
}

void MotionController::setTargetVelocity(float target_deg_s) {
    _target_vel_deg_s = target_deg_s;
}

void MotionController::setPIDGains(float kp, float ki, float kd) {
    _pid.kp = kp;
    _pid.ki = ki;
    _pid.kd = kd;
}

void MotionController::enable(bool state) {
    if (state) {
        setControlMode(ControlMode::CLOSED_LOOP_POSITION);
    } else {
        setControlMode(ControlMode::MOTOR_DISABLED);
    }
}

void MotionController::emergencyStop() {
    _target_vel_deg_s = 0.0f;
    _target_pos_deg = _encoder.getMultiTurnAngle() * DEG_PER_COUNT;
    _current_setpoint_deg = _target_pos_deg;
    _integral_error = 0.0f;
    setControlMode(ControlMode::TORQUE_HOLD);
}

float MotionController::getTargetPosition() {
    return _target_pos_deg;
}

float MotionController::getTargetVelocity() {
    return _target_vel_deg_s;
}

float MotionController::getPositionError() {
    float measured = _encoder.getMultiTurnAngle() * DEG_PER_COUNT;
    return _target_pos_deg - measured;
}

int32_t MotionController::getStepCount() {
    return _step_count;
}

ControlMode MotionController::getControlMode() {
    return _control_mode;
}

void MotionController::singleStep(bool forward) {
    if (forward) {
        if (_direction != 1) {
            digitalWrite(PIN_TMC_DIR, HIGH);
            _direction = 1;
            delayMicroseconds(1);
        }
        _step_count++;
    } else {
        if (_direction != -1) {
            digitalWrite(PIN_TMC_DIR, LOW);
            _direction = -1;
            delayMicroseconds(1);
        }
        _step_count--;
    }

    digitalWrite(PIN_TMC_STEP, HIGH);
    delayMicroseconds(2);
    digitalWrite(PIN_TMC_STEP, LOW);
}

void MotionController::update() {
    if (_control_mode == ControlMode::MOTOR_DISABLED) {
        return;
    }

    uint32_t now_us = micros();
    float dt = (now_us - _last_loop_us) / 1000000.0f;
    if (dt <= 0.0f || dt > 0.05f) dt = 0.001f;
    _last_loop_us = now_us;

    _encoder.update();
    float measured_pos = _encoder.getMultiTurnAngle() * DEG_PER_COUNT;

    float command_velocity = 0.0f;

    switch (_control_mode) {
        case ControlMode::CLOSED_LOOP_POSITION: {
            float error = _target_pos_deg - measured_pos;
            _integral_error += error * dt;
            if (_integral_error > _pid.max_integral) _integral_error = _pid.max_integral;
            if (_integral_error < -_pid.max_integral) _integral_error = -_pid.max_integral;

            float derivative = (error - _last_error) / dt;
            _last_error = error;

            // PID calculation
            command_velocity = (_pid.kp * error) + (_pid.ki * _integral_error) + (_pid.kd * derivative);

            // Clamp maximum output velocity
            if (command_velocity > _pid.max_output) command_velocity = _pid.max_output;
            if (command_velocity < -_pid.max_output) command_velocity = -_pid.max_output;

            // Deadband to prevent jitter when positioned accurately
            if (fabs(error) < 0.05f) {
                command_velocity = 0.0f;
            }
            break;
        }

        case ControlMode::CLOSED_LOOP_VELOCITY: {
            float measured_vel = _encoder.getVelocityDegPerSec();
            float error_vel = _target_vel_deg_s - measured_vel;
            command_velocity = _target_vel_deg_s + (_pid.kp * error_vel * 0.2f);
            break;
        }

        case ControlMode::OPEN_LOOP_VELOCITY: {
            command_velocity = _target_vel_deg_s;
            break;
        }

        case ControlMode::TORQUE_HOLD: {
            command_velocity = 0.0f;
            break;
        }

        default:
            command_velocity = 0.0f;
            break;
    }

    if (fabs(command_velocity) > 0.1f) {
        generateSteps(command_velocity, dt);
    }
}

void MotionController::generateSteps(float velocity_deg_s, float dt) {
    // Convert deg/s to steps/s
    float steps_per_deg = (float)STEPS_PER_REV_NEMA / 360.0f;
    float steps_to_run = velocity_deg_s * steps_per_deg * dt;

    int32_t count = (int32_t)fabs(steps_to_run);
    bool forward = (velocity_deg_s >= 0.0f);

    for (int32_t i = 0; i < count; i++) {
        singleStep(forward);
    }
}

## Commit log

2026-07-24 Sync schematic footprint assignments 1:1 from PCB file
    [436500201.step, 436500212.step, ESP32-S3-MINI-1-N4R2.step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]
2026-07-24 Updated SW1-SW4, U6, J2 footprints & values in both schematic and PCB files
    [canbus-stepper.kicad_pcb, canbus-stepper.kicad_sch]
2026-07-24 feat: complete hardware schematic fixes, 0603 footprint optimizations, AS5600 encoder, TCAN1051V transceiver, and IPC-2221 design rules
    [canbus-stepper.kicad_pcb, canbus-stepper.kicad_sch]
2026-07-25 feat: update schematic and pcb layout design files
    [canbus-stepper.kicad_pcb, canbus-stepper.kicad_sch]
2026-07-25 feat: set exact datasheet values for all passive resistors (R1-R17) and capacitors (C1-C15)
    [canbus-stepper.kicad_pcb, canbus-stepper.kicad_sch]
2026-07-25 feat: add 24V PPTC fuse, P-FET reverse polarity protection, USB PPTC fuse, CAN TVS, and USB ESD arrays
    [canbus-stepper.kicad_pcb, canbus-stepper.kicad_sch]
2026-07-25 fix: remove invalid property-level uuid fields to fix KiCad schematic loading error
    [canbus-stepper.kicad_sch]
2026-07-25 fix: embed graphical symbol definitions in lib_symbols for F1, F2, Q1, D4, D5, U7 to eliminate question mark boxes
    [canbus-stepper.kicad_pcb, canbus-stepper.kicad_sch]
2026-07-25 fix: resolve D5 footprint name to Package_TO_SOT_SMD:SOT-23, map Q1 SOIC-8 8-pins, and add pin UUID instances
    [canbus-stepper.kicad_pcb, canbus-stepper.kicad_sch]
2026-07-25 fix: resolve D5 footprint name to Package_TO_SOT_SMD:SOT-23, fix Q1 SOIC-8 8-pin mapping, and retain all schematic symbols
    [canbus-stepper.kicad_sch]
2026-07-25 chore: save PCB editor update state prior to unplaced component grouping
    [canbus-stepper.kicad_pcb]
2026-07-25 style: arrange unplaced PCB components into 8 functional matrix groups outside board boundary
    [canbus-stepper.kicad_pcb]
2026-07-25 fix: resolve D5 SOD-123 footprint, add F1/F2 fuse net wiring, and map thermal/shield pads for ESP32, TCAN1051, J2, J8, J9, SW1-SW4 to eliminate all warnings and errors
    [canbus-stepper.kicad_pcb, canbus-stepper.kicad_sch]
2026-07-25 fix: fix schematic pin 41 parenthesis syntax error and balance all parens
    [canbus-stepper.kicad_sch]
2026-07-25 fix: restore embedded_fonts syntax hierarchy within ESP32 symbol block
    [canbus-stepper.kicad_sch]
2026-07-25 fix: resolve D5 SOD-123 2-pin footprint and clean up Conn_01x04 & SW_Push pin mappings to eliminate all 24 footprint pad errors
    [canbus-stepper.kicad_sch]
2026-07-25 fix: connect J8 24V input and J1 USB VBUS to fuse nets F1 and F2
    [canbus-stepper.kicad_pcb, canbus-stepper.kicad_sch]
2026-07-25 chore: save board and schematic progress before autoplacer development
    [canbus-stepper.kicad_pcb, canbus-stepper.kicad_sch]
2026-07-25 update canbus ohm sw footprint
    [canbus-stepper.kicad_pcb, canbus-stepper.kicad_sch]
2026-07-26 full revision of net connection, components
    [436500209.step, AS5600-ASOT.step, JS102011JCQN.step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]
2026-07-26 refactor: reorganize project structure into pcb, docs, firmware, and step directories
    [436500201.step, 436500209.step, 436500212.step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]
2026-07-26 docs: add CC BY-NC-SA 4.0 license with commercial restriction and embed PCB preview image in README
2026-07-26 docs: rename PCB preview assets to pcb_top.png and pcb_bottom.png and render side-by-side in README
2026-07-27 docs: update README to reflect ESP32-S3 MCU and updated QFN components
2026-08-04 feat(pcb): add Net Classes rules, project symbol library and switch revisions
    - Configure PCB Net Classes (Power_24V, Motor_Phases, Power_Low, HighSpeed_Diff, Default) and routing presets.
    - Create unified project symbol library (CANBUS-Stepper.kicad_sym) and SW_TS31-46-35-BK-B-160-RA-SMT-TR switch symbol, registered in sym-lib-table.
    - Update SW2 (SW_TS31) and S1 (SLW-66527511) switch symbols and footprint assignments in schematic.
    - Add temporary DSN file pattern to .gitignore.
2026-08-04 feat(pcb): update symbol library footprints and import all downloaded symbols
    - Consolidate all 23 custom symbols into CANBUS-Stepper.kicad_sym library.
    - Update default Footprint properties for all 23 symbols to point to CANBUS-Stepper:<FootprintName>.
    - Fix AON7407 DFN-8 symbol pin mapping using stacked pins (5, 6, 7, 8).
    - Register all symbol libraries in sym-lib-table to preserve existing schematic references.
    - Add KiCad autosave file pattern to .gitignore.
2026-08-11 chore: ignore pcb directory from public repository
2026-08-12 docs: append cache buster to PCB preview images in README
2026-08-15 feat(hardware): transition project to 100% Open-Source Hardware (OSHW), integrate PCB source files and update licensing
    [bom.csv, canbus-stepper.csv, canbus-stepper.kicad_pcb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]
2026-08-16 feat(firmware): implement ESP32-S3 closed-loop control stack, TWAI CAN protocol, TMC2209/AS5600 drivers and Klipper/Micro-ROS integration
    [canbus_stepper_klipper.cfg]
2026-08-18 feat(hardware): transition to MKS hybrid model, decouple PCB repo & provide reference schematic PDF
    [bom.csv, canbus-stepper.csv, canbus-stepper.kicad_pcb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]
2026-08-18 fix(docs): normalize hardware and firmware revisioning to v1.0 across repository
    [canbus_stepper_klipper.cfg]
2026-08-18 docs: correct SM02B-SRSS-TB connector description to CAN Bus In/Out
2026-08-29 release(firmware): update pin definitions to v1.1 production layout
    [canbus_stepper_klipper.cfg]
2026-08-29 release(v1.1): update documentation, 3D STEP models, schematics and firmware to v1.1
    [canbus_stepper_klipper.cfg]
2026-08-31 release(v1.1): update Q1 to AON7410, sync schematics and 3D models
2026-09-02 release(v1.1): update schematic PDF with TCAN3413, AON7403, and FNR4020 fixes
2026-09-03 docs(v1.1): align README, schematics docs, and firmware comments with v1.1 hardware changes
    - Update CAN transceiver model to TI TCAN3413 (3.3V logic) in README, docs, and firmware logs
    - Update reverse polarity MOSFET to AON7403 (-30V P-Channel)
    - Add FNR4020S4R7MT shielded power inductor to buck converter specs
    - Update v1.1 schematic PDF and STEP 3D CAD document links
    [can_protocol.cpp, config.h, main.cpp]

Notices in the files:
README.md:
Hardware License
